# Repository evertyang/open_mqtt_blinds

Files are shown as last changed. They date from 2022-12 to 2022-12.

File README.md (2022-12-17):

# Open MQTT Blinds

An Arduino/ESP-based project to facilitate the automation of tilt wand blinds via MQTT



## Printables

View the 3D files here on [Printables](https://www.printables.com/model/334239-open-mqtt-blinds-wip). 

# Who is this for?

Anyone with a beginner’s level of mechatronics experience who wishes to automate their tilt wand blinds. 

![[https://www.blindschalet.com/bpa-423-industry-changes-stock-blinds-shades-december-2018.html](https://www.blindschalet.com/bpa-423-industry-changes-stock-blinds-shades-december-2018.html)](images/Untitled.png)

[https://www.blindschalet.com/bpa-423-industry-changes-stock-blinds-shades-december-2018.html](https://www.blindschalet.com/bpa-423-industry-changes-stock-blinds-shades-december-2018.html)

# Prerequisites

## Hardware

- Required:
    - [ESP8226 Board](https://smile.amazon.com/dp/B010N1SPRK?psc=1)
    - [28BYJ-48 Stepper Motor + ULN2003 Driver Combo](https://smile.amazon.com/dp/B01IP7IOGQ?psc=1)
    - [Buck Converter](https://www.amazon.com/LM2596-Converter-4-0-40V-1-25-37V-Voltmeter（2pcs）/dp/B085WC5G8N/ref=sr_1_3?crid=3Q47218J1UTVY&keywords=buck+converter&qid=1670349659&sprefix=buck+converter%2Caps%2C83&sr=8-3)
    - [Female-to-Female Jumper Wires](https://www.amazon.com/GenBasic-Piece-Female-Jumper-Wires/dp/B077N58HFK/?sprefix=female+to+female+dup,aps,110)
    - [12V DC power supply](https://www.amazon.com/100-240V-Transformers-Switching-Applications-Connectors/dp/B077PW5JC3/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,aps,108)
        - There is a good chance you have one of these lying around. Be sure the output is listed as 12v 3A.
    - [DC Barrel Jack to 2 Pin](https://www.amazon.com/dp/B07LFRDSB7?psc=1&ref=ppx_yo2ov_dt_b_product_details)
        - (if you didn’t purchase the above)
    - Metric screws:
        - (4) M2x8
        - (6) M2x4
        - (2) M3x4
- Nice to haves:
    - Access to a 3D printer OR the ability to get 3D printed parts
    - [Wire strippers](https://www.amazon.com/IRWIN-VISE-GRIP-2078300-Self-Adjusting-Stripper/dp/B000OQ21CA)
    - [Dupont connector kit to create your own length wires](https://www.amazon.com/IWISS-1550PCS-Connector-Headers-Balancer/dp/B08X6C7PZM/?sprefix=dupon,aps,102)
    - [Connector crimper for the above](https://www.amazon.com/dp/B017JU20Z6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)
    - [Ferrule crimping set so you don’t have to connect bare wires to pins](https://www.amazon.com/gp/product/B073TZ5BBG/ref=ppx_yo_dt_b_search_asin_title?ie=UTF8&psc=1)

## Software

- [Arduino IDE](https://www.arduino.cc/en/software)
- [Home Assistant](https://www.home-assistant.io) (HA)
    - I won’t go through specific installation steps here as it can be installed on a wide array of platforms
    - This project does necessitate the use of Add-Ons which means an OS or Supervised installation is required
        
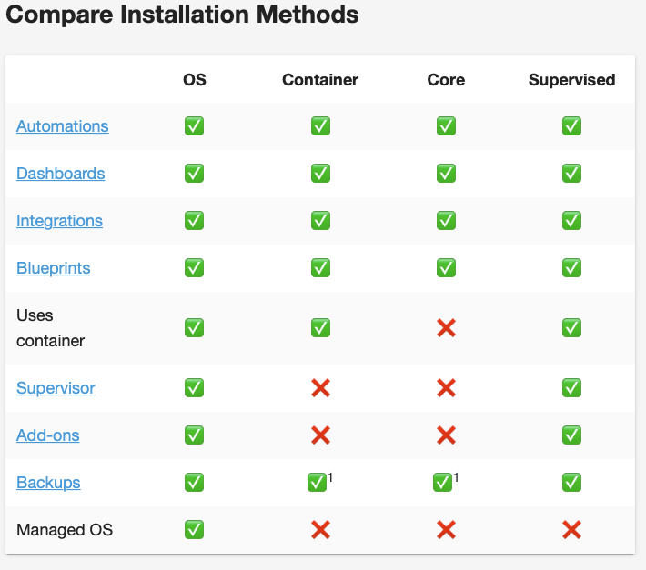
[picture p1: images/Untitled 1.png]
[https://www.home-assistant.io/installation/](https://www.home-assistant.io/installation/)
        
        
        [https://www.home-assistant.io/installation/](https://www.home-assistant.io/installation/)
        
    - I am running HA as a Linux VM
    - HA Installation documentation can be found [here](https://www.home-assistant.io/installation)
    - I found this [YouTube video](https://youtu.be/sVqyDtEjudk) to be very helpful when setting up HA
- [HA - MQTT Broker](https://www.home-assistant.io/integrations/mqtt/)
    - I will go through installation in the setup section

# Setup

## Home Assistant - MQTT Broker

1. It assumed at this point that you have Home Assistant installed and you are able to access the GUI via local IP address 
2. Navigate to *****Settings → Add-Ons → Add-Ons Store***** and look for **Mosquitto broker**
    
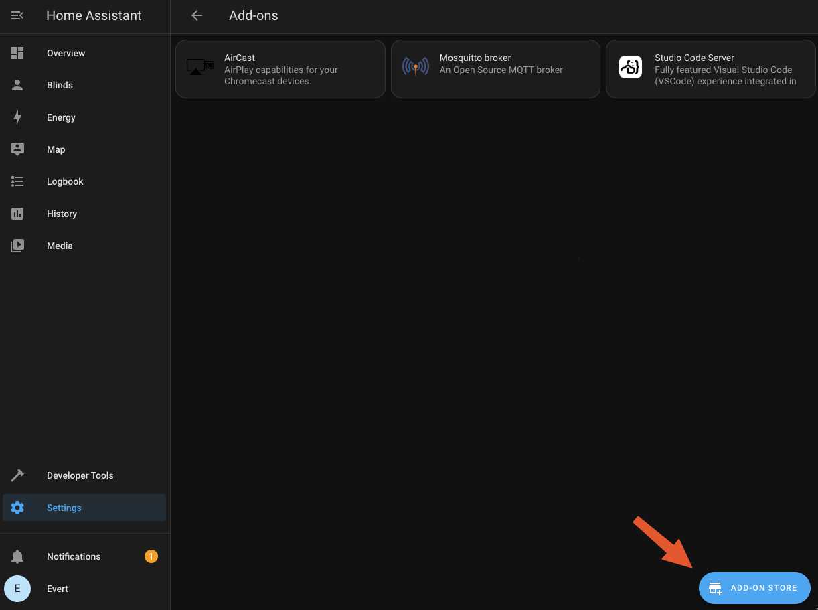
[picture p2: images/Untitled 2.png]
    
    
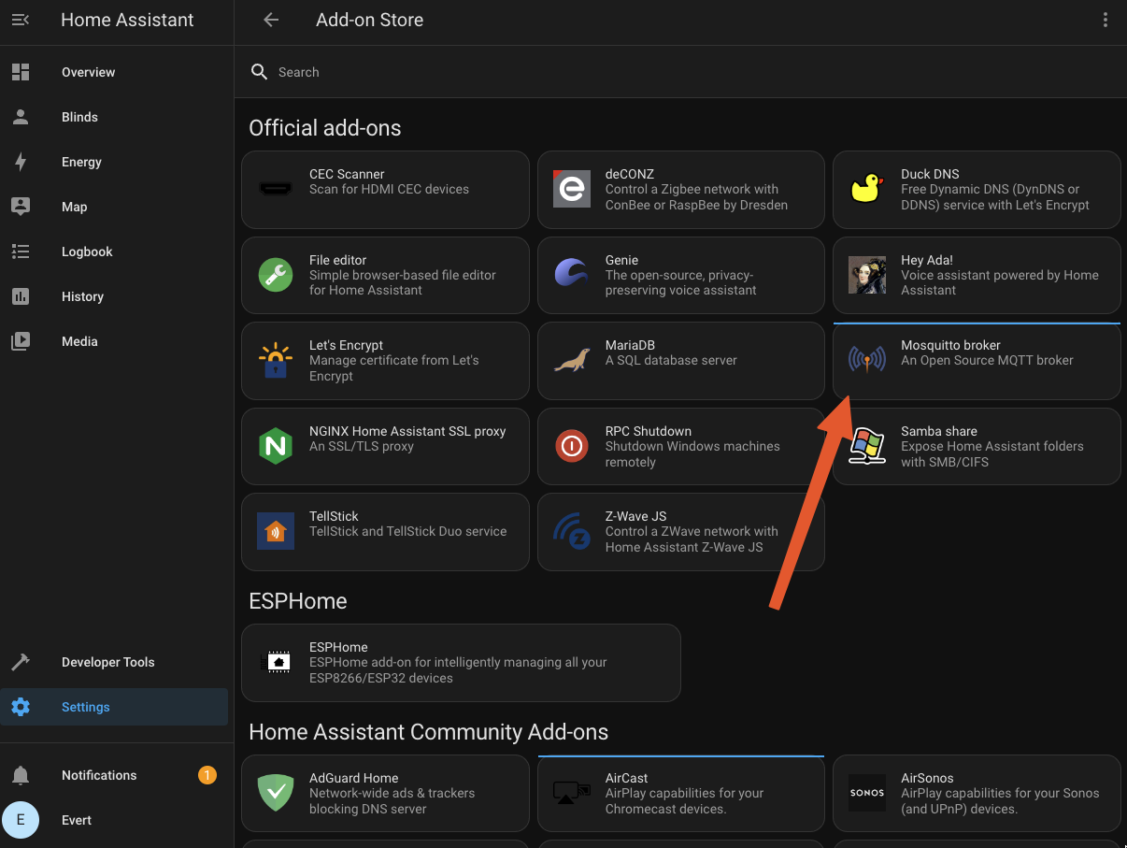
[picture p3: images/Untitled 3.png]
    
    
3. Click install and check the *Watchdog* option
    
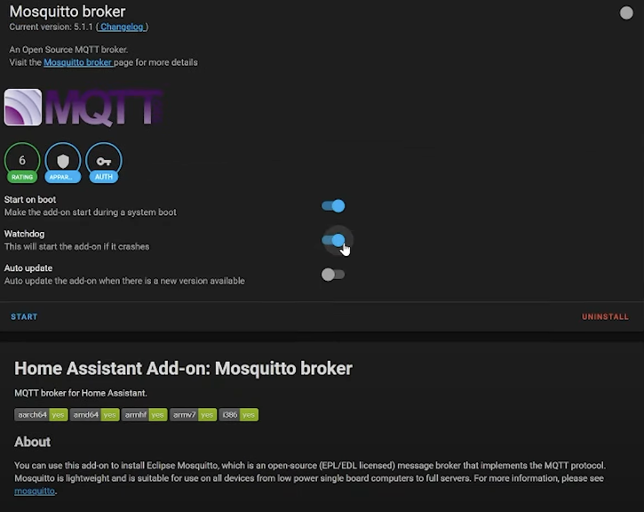
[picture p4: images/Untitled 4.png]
    
    
4. Create a MQTT user
    1. It’s considered best practice to create another user account for MQTT as it does not need admin access
    2. Navigate to ***Settings → People*** and click Add Person
        
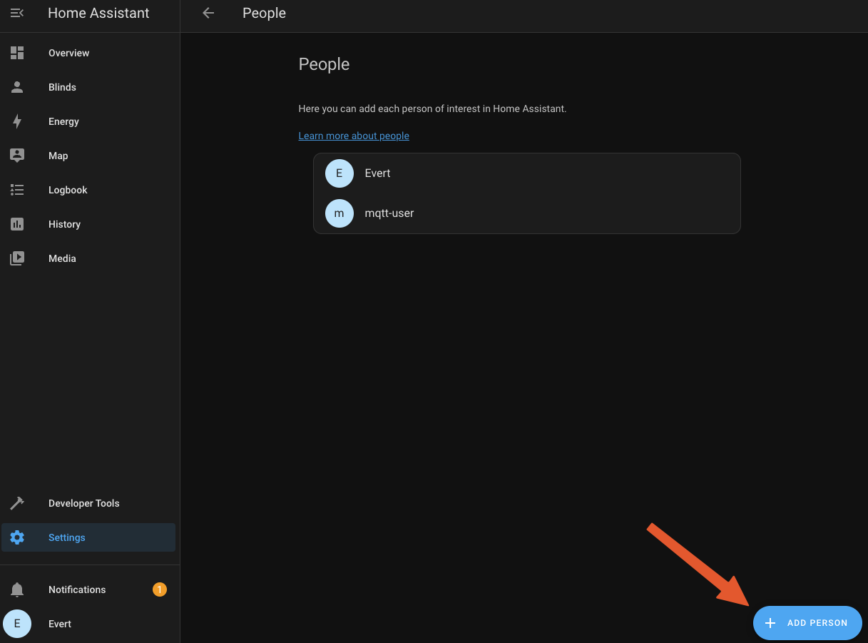
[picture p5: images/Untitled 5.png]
        
        
    3. Hit the *******Allow person to login******* toggle and create a MQTT user. I name mine `mqtt-user`. 
        
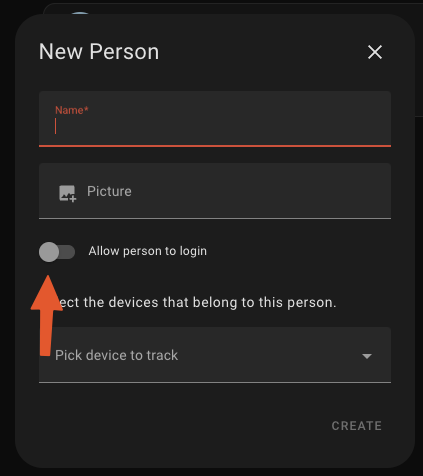
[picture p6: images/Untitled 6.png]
        
        
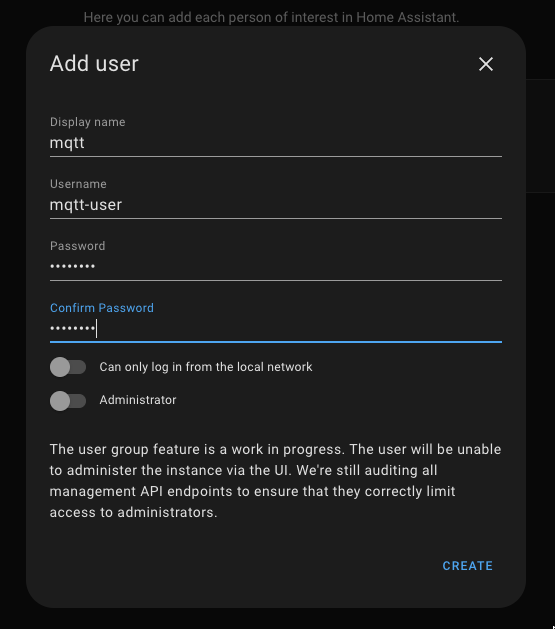
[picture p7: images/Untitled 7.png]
        
        
    4. Be sure to save these credentials in your password manager for later. 
5. Restart your Home Assistant instance via ***Settings → System*** and click Restart. 
    
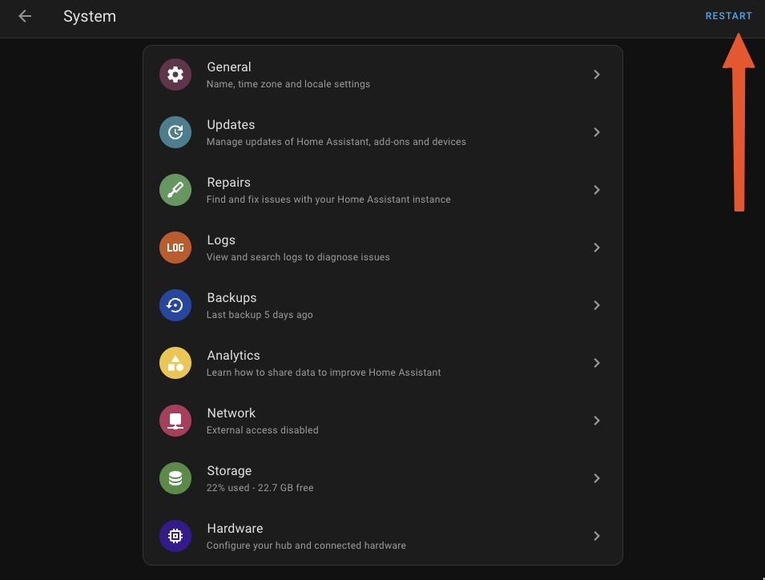
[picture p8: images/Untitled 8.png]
    
    
6. After restarting, you should see MQTT added to your Integrations Tab under ****Settings → Devices & Services**** 
    
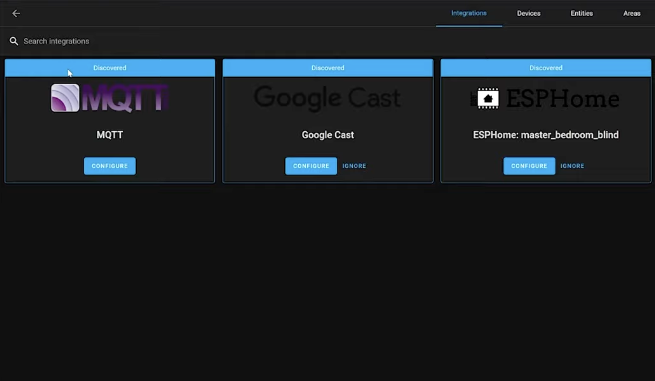
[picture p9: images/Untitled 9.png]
    
    
7. Click Configure and Submit followed by Configure once again to enter the integration
    
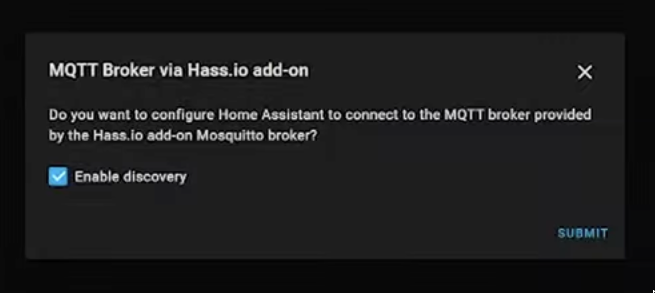
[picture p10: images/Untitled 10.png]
    
    
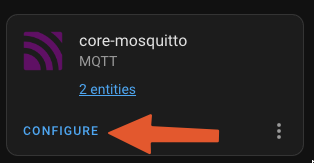
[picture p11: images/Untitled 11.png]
    
    
8. Click Re-Configure and add your MQTT user credentials from before
    
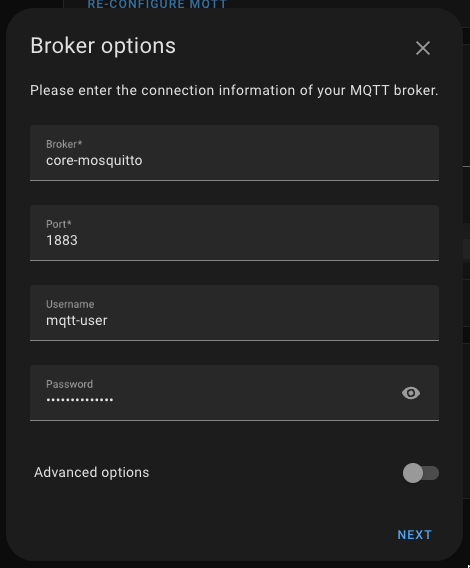
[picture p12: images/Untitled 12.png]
    
    
9. From this page you can send payloads via MQTT as well as monitor topics. This can be helpful later on for debugging any issues. 
    
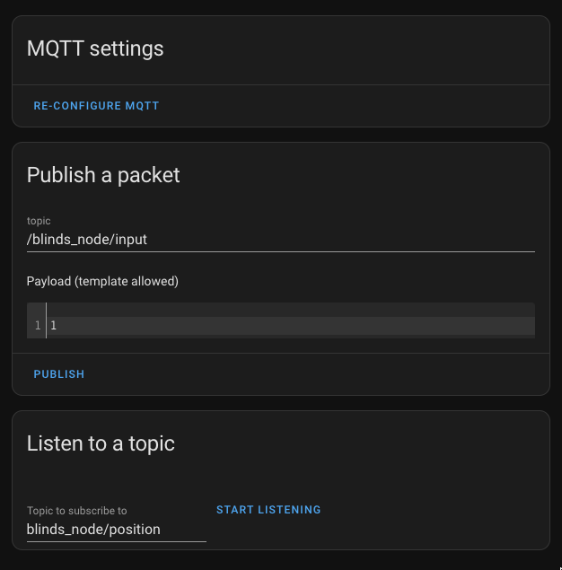
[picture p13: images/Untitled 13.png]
    

## Arduino IDE

1. Install Arduino IDE onto your platform of choice 
2. Add ESP8226 to board manager
    1. Navigate to preferences and paste `https://arduino.esp8266.com/stable/package_esp8266com_index.json` into ********Additional Board Manager URLs********
        
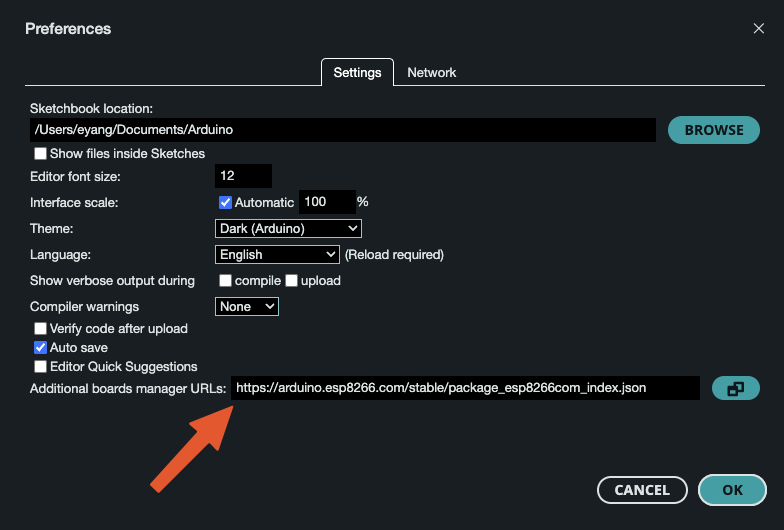
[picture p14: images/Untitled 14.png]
        
        
    2. Select ****NodeMCU 0.9**** as your board and hit OK. If you have connected your board via USB you can also select the port containing the board and hit OK. 
        
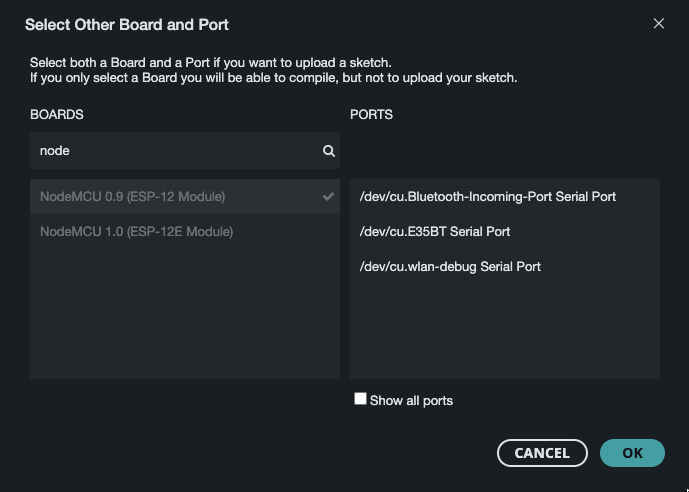
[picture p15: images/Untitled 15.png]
        
        
    3. If you prompted with this pop-up, click Yes
        
        
        
3. Import `mqtt_stepper.ino`
    1. Open `mqtt_stepper.ino` in Arduino IDE
    2. The required packages defined at the top of file should be automatically installed 
        1. If not, you will have to install them manually via the Library Manager
            
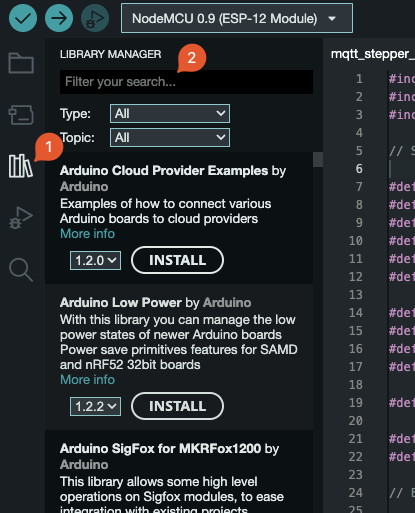
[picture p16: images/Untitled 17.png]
            
            
4. Fill out the user configuration section
    1. `USER_MQTT_URL` will be your Home Assistant GUI URL
    2. `USER_MQTT_USERNAME` and `USER_MQTT_PASSWORD` are the credentials you saved when creating a MQTT user
    3. `STEPS_PER_REV` should be set to `2048` if using a 28BY J-45 Stepper motor. If using another, see relevant technical information for correct number of steps
    4. `REVS_TO_CLOSE` will vary by blinds model. You can set this to `1` during the initial setup and tune it as necessary. 
    5. All other definitions can be left as written. 
    
    ```cpp
    // START USER CONFIG
    
    #define WIFI_SSID "your_wifi_name"
    #define WIFI_PASS "your_wifi_password"
    #define USER_MQTT_URL "xxx.xxx.xxx.xxx"
    #define USER_MQTT_PORT 1883
    #define USER_MQTT_USERNAME "your_mqtt_username"
    #define USER_MQTT_PASSWORD "your_mqtt_password"
    
    #define STEPPER_IN1 D5
    #define STEPPER_IN2 D6
    #define STEPPER_IN3 D7
    #define STEPPER_IN4 D8
    
    #define MSG_BUFFER_SIZE (50)
    
    #define STEPS_PER_REV 2048
    #define REVS_TO_CLOSE 8
    
    // END USER CONFIG
    ```
    
5. Connect the ESP8226 board via micro-USB if not already connected 
6. Click Upload and Arduino IDE will compile and send the sketch to the ESP8226 Board
    1. You should see it’s status in the output monitor 
    
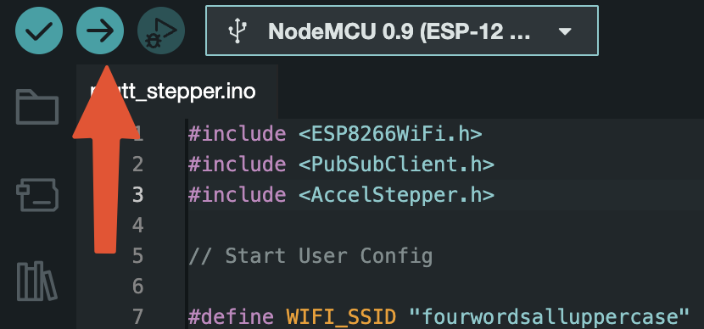
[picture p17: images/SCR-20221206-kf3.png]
    
    
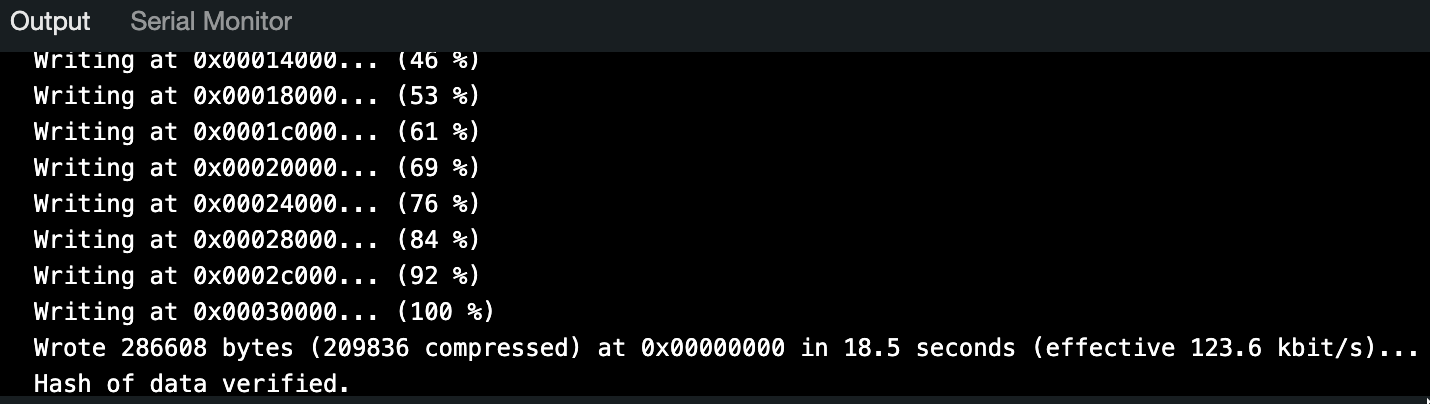
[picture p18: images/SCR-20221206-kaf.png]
    
    
7. Click the Serial Monitor button in the top right of screen and set the baud rate to `115200` 
    1. You should see connection status of board being outputted
    
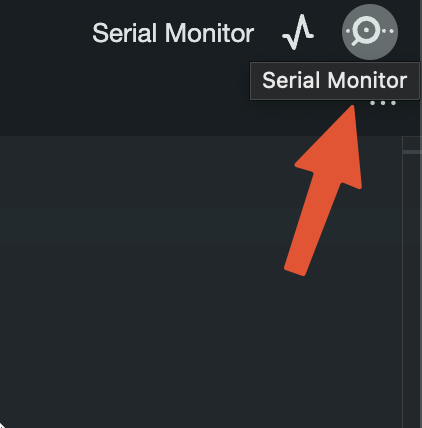
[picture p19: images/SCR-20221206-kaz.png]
    
    
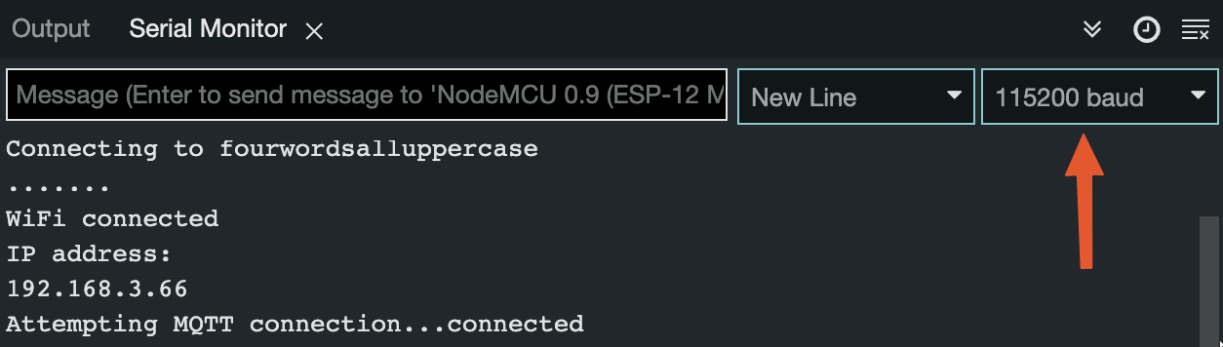
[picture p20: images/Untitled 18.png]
    
    
8. You can verify that it can receive MQTT payloads by sending one via the MQTT integration in Home Assistant
    
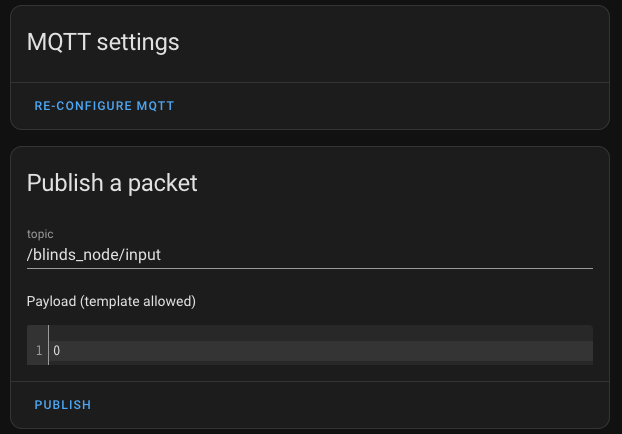
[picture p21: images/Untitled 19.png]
    
    
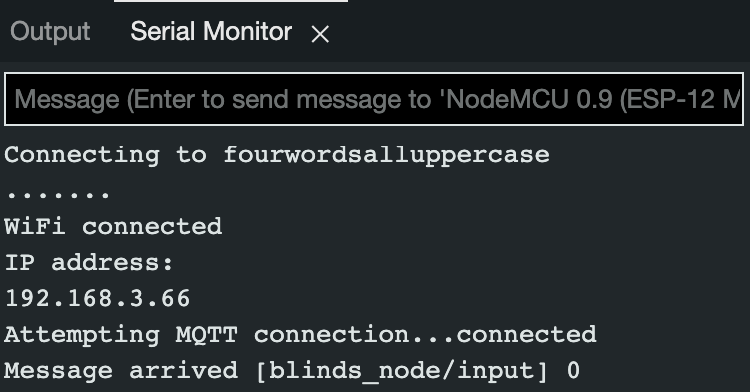
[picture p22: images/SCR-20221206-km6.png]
    

## Assembly

1. Download and print `controller_box.3mf` and `adapter.3mf`
    1. The controller box was designed to use as few supports as possible so material choice should not matter
    2. My parts were printed in Overture Matte White PLA at 210C
2. Place each board onto their respective stand-offs and screw on to secure boards in-place
    1. I found it easier to first screw each board down before assembling the box sides
        
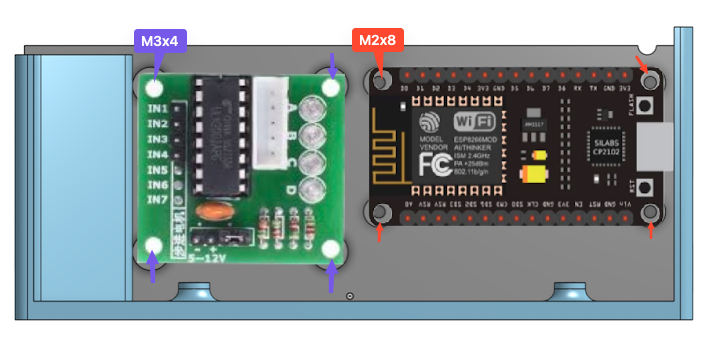
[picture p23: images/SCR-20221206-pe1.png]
NOTE: the ESP8226 board will be flipped when actually installed, with its pins facing away from the wall. Refer to wiring schematic for correct wire connections.
        
        
        NOTE: the ESP8226 board will be flipped when actually installed, with its pins facing away from the wall. Refer to wiring schematic for correct wire connections. 
        
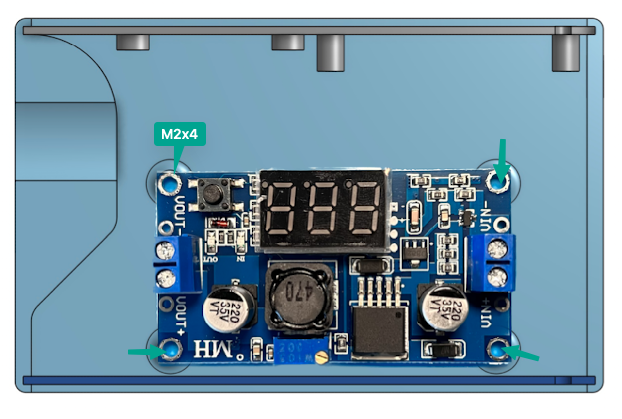
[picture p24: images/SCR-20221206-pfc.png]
        
        
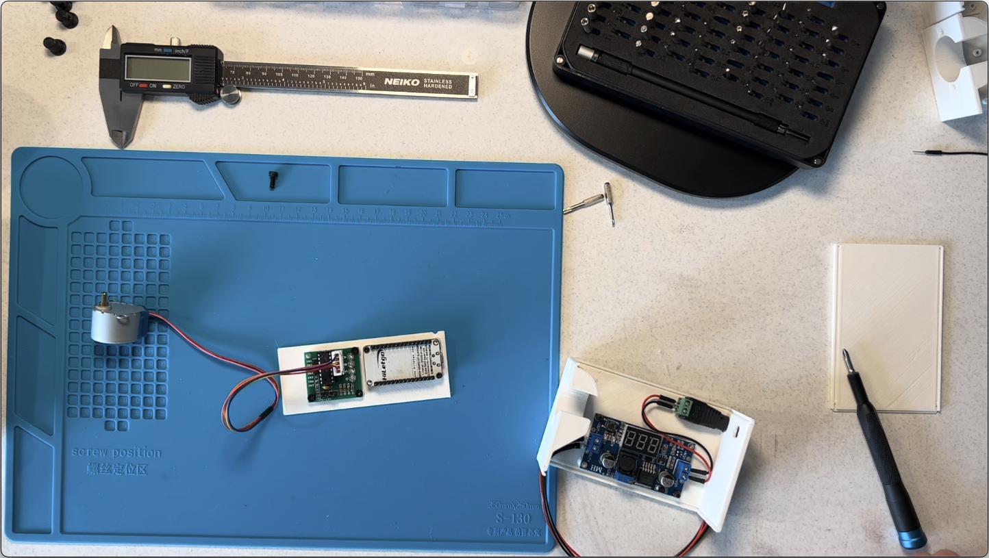
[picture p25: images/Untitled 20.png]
        
        
3. Wire up the components according the following schematic:
    1. Ensure that the buck convert is set to output 5V before connecting it any other components 
        
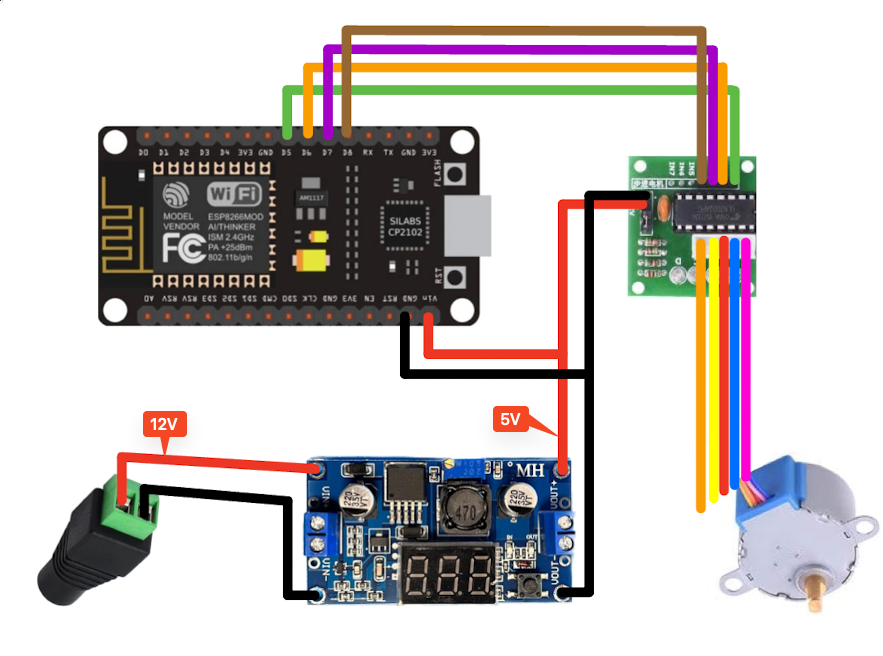
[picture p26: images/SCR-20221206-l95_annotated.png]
        
        
4. Once all connections have been made, plugging in power should result in the board and buck converter LEDs turning on
    
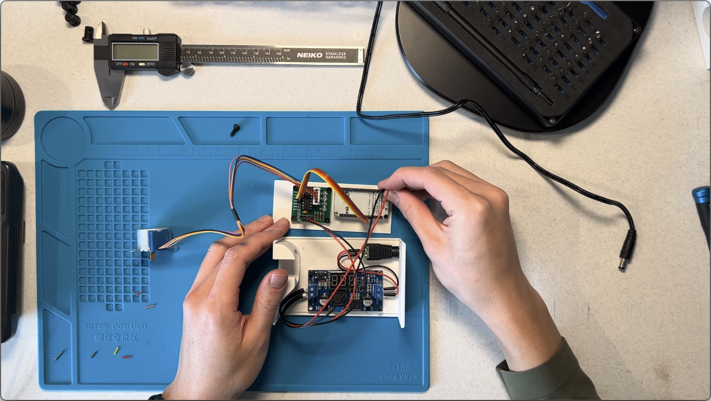
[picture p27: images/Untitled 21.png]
    
    
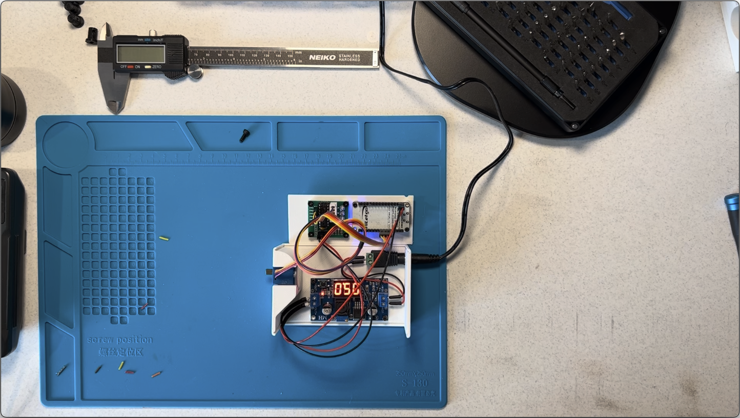
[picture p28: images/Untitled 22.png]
    
    
5. At this point, you can either continue with assembly of controller box or move onto Home Assistant configuration to validate it works final assembly
6. Finish box assembly by sliding each of the side walls into the grooves on either side of case
    1. There will be some resistance but take care not to use too much force to avoid breaking the case or electronics
        
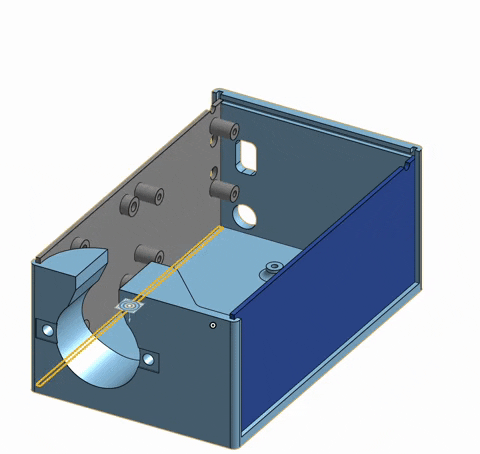
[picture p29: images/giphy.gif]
        
        
    2. Place the stepper motor into its slot and secure with (2) M3x4 screws
        
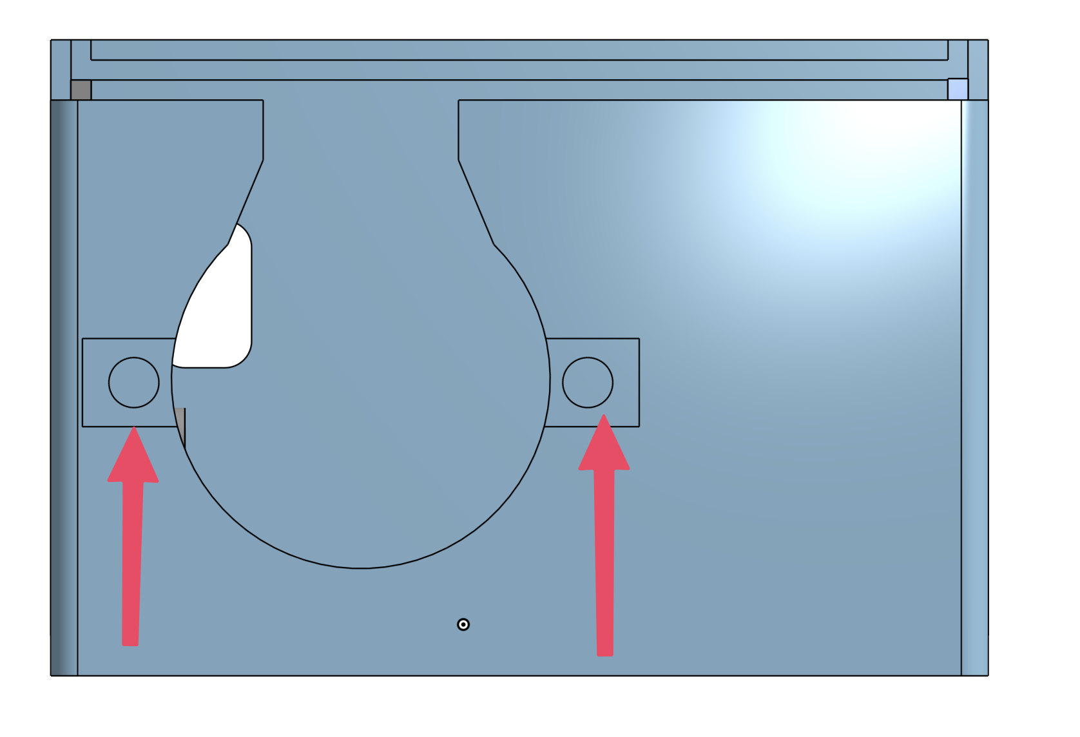
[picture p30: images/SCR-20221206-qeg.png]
        
        
    3. Top with lid and controller box assembly is complete 
        
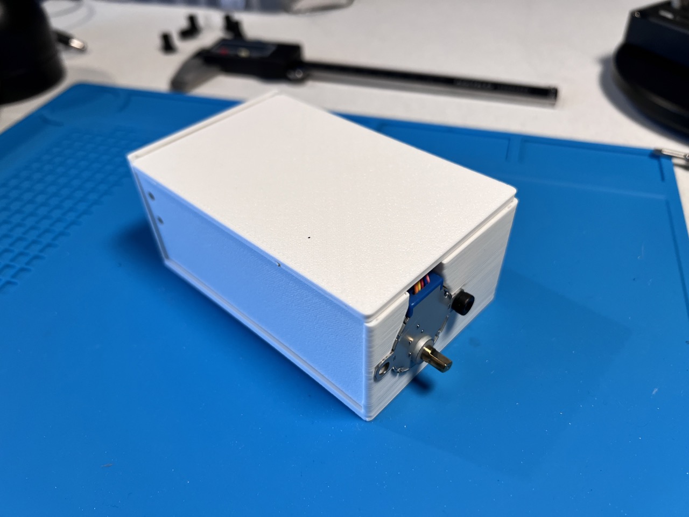
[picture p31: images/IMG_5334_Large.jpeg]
Prototype shown missing a screw
        
        
        Prototype shown missing a screw
        
7. Assemble the wand adapter
    1. Use a small screw driver or similarly shaped tool to depress the plastic notch securing the wand’s end cap 
        
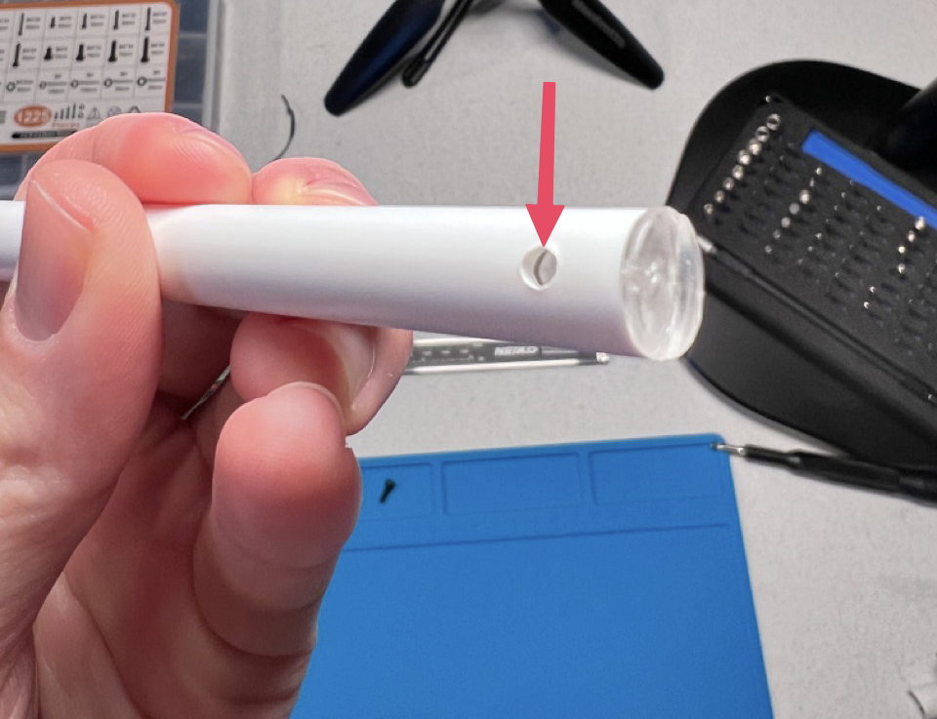
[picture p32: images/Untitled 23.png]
        
        
    2. Line up the adapter hole with the wand hole and secure with one M2x8 screw
8. Mounting the box
    1. Using your choice of double sided adhesive, mount the box under the wand taking care to keep the angle as roughly parallel to maximize torque
        
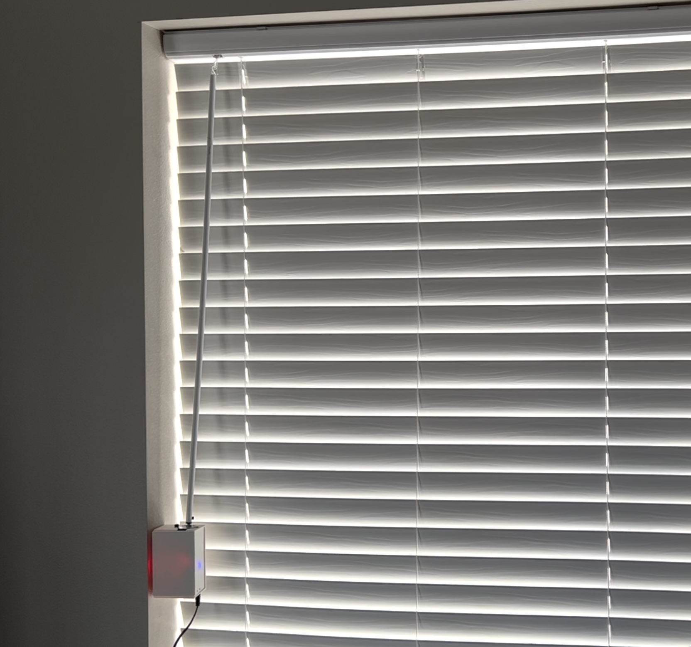
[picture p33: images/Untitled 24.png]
        
        
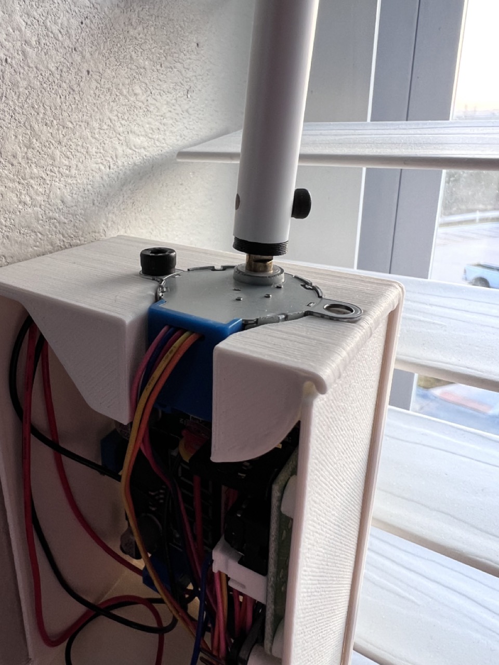
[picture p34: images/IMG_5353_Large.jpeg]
        
        
    2. 

## Home Assistant - Adoption

1. Return to the Home Assistant WebUI and navigate to Add-Ons Store once again to install Studio Code Server
    
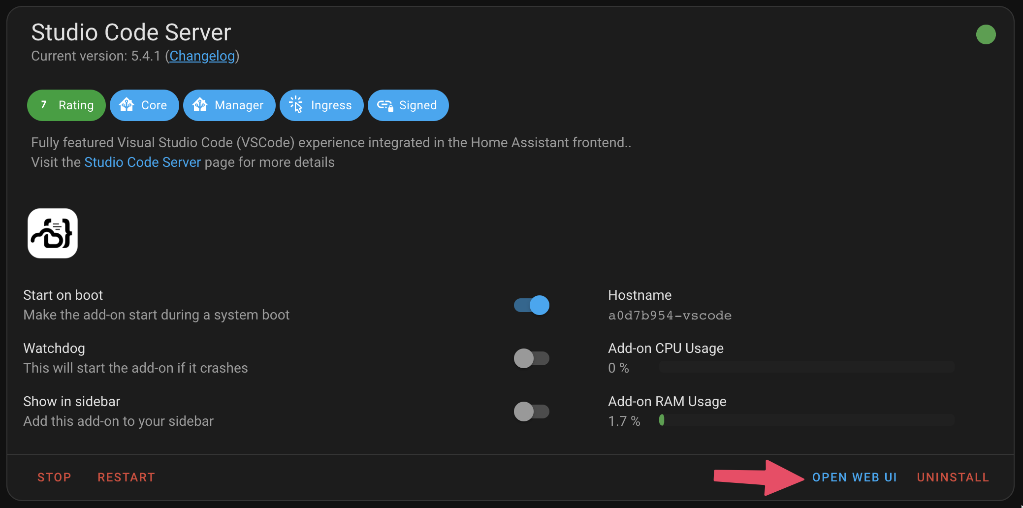
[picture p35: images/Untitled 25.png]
    
    
2. Open the Studio Code Server Web UI
    1. Once it has finished its first-time setup, use the Explorer to open `configuration.yaml`
        
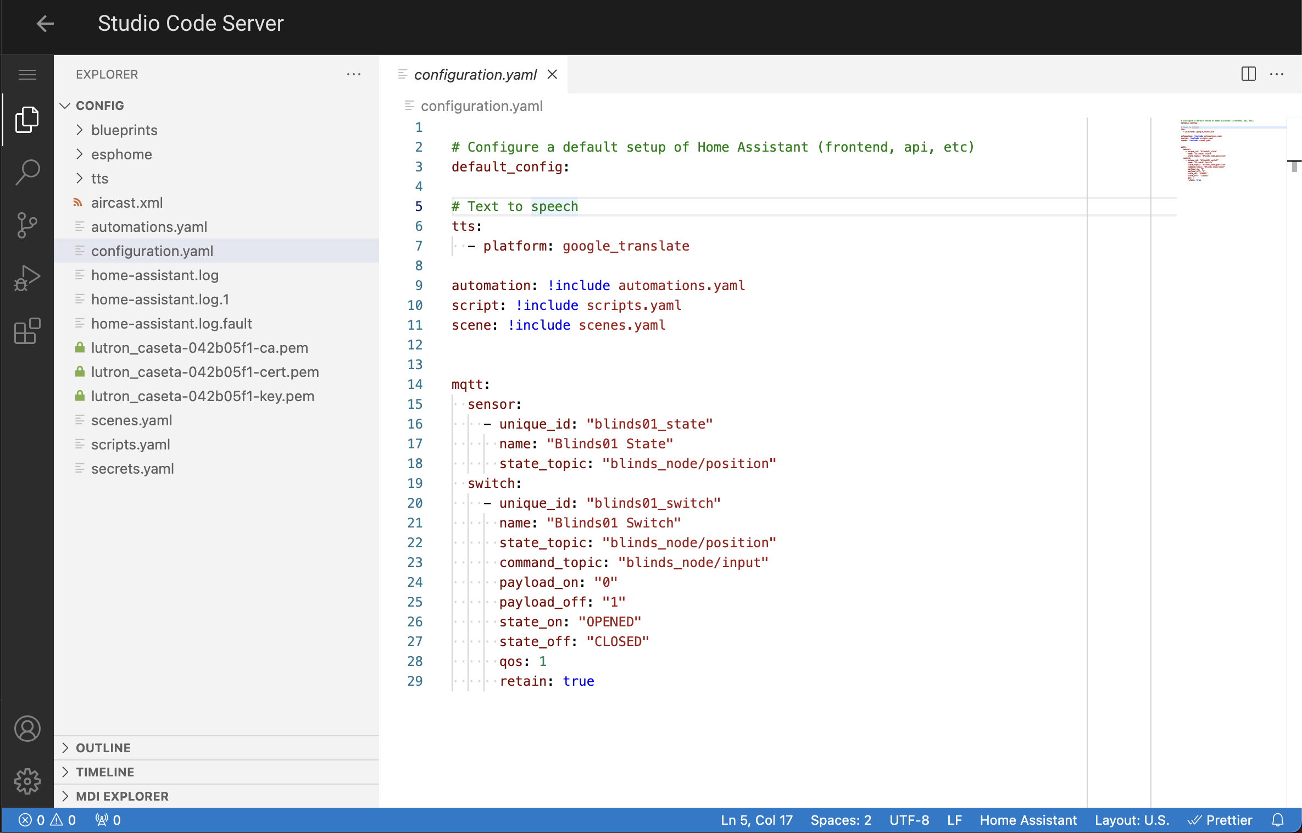
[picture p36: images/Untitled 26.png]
        
        
    2. Add the following code to the end of the line:
    
    ```yaml
    mqtt:
      sensor:
        - unique_id: "blinds01_state"
          name: "Blinds01 State"
          state_topic: "blinds_node/position"
      switch:
        - unique_id: "blinds01_switch"
          name: "Blinds01 Switch"
          state_topic: "blinds_node/position"
          command_topic: "blinds_node/input"
          payload_on: "0"
          payload_off: "1"
          state_on: "OPENED"
          state_off: "CLOSED"
          qos: 1
          retain: true
    ```
    
3. Restart your Home Assistant instance via *Settings* → *System* and click Restart.
4. You should now see 2 new entities added to your Home Assistant Dashboard
    
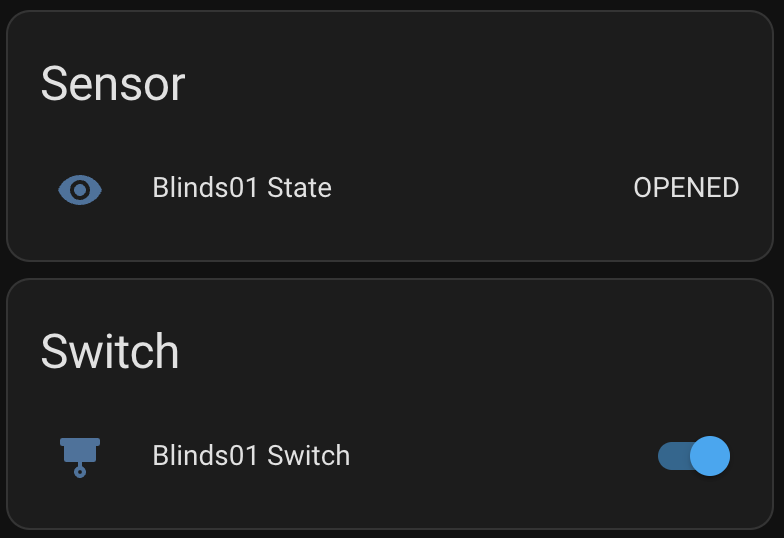
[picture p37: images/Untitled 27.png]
    
    
5. You should now able to send MQTT payloads via this switch to blinds controller 
    1. You can use MQTT integration to monitor payloads being sent 
        
        

## Adding it HomeKit

1. Install HomeKit Bridge integration following these [instructions](https://www.home-assistant.io/integrations/homekit#setup)
    1. Return to the integrations tab and hit Add Integration
    2. Search for Apple → HomeKit
    
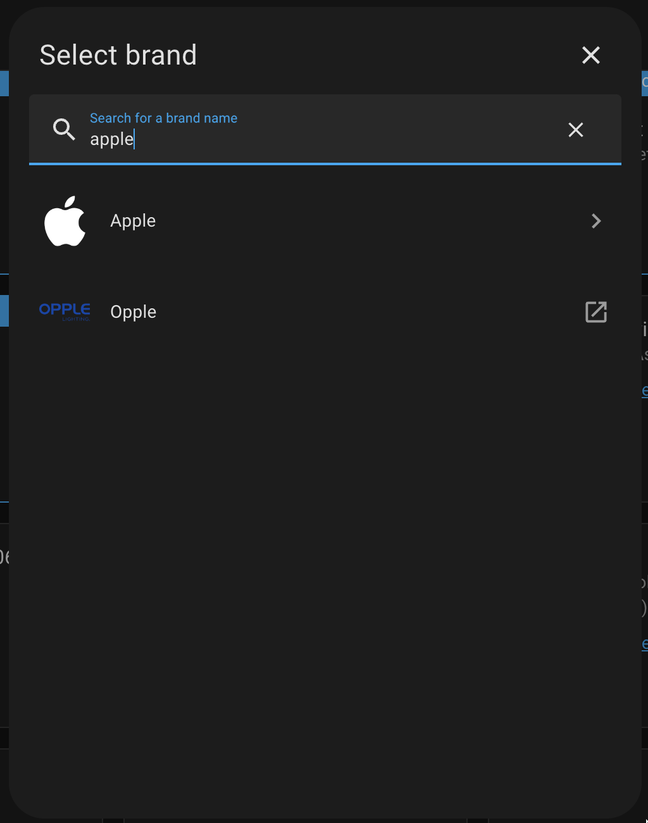
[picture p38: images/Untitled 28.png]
    	
    
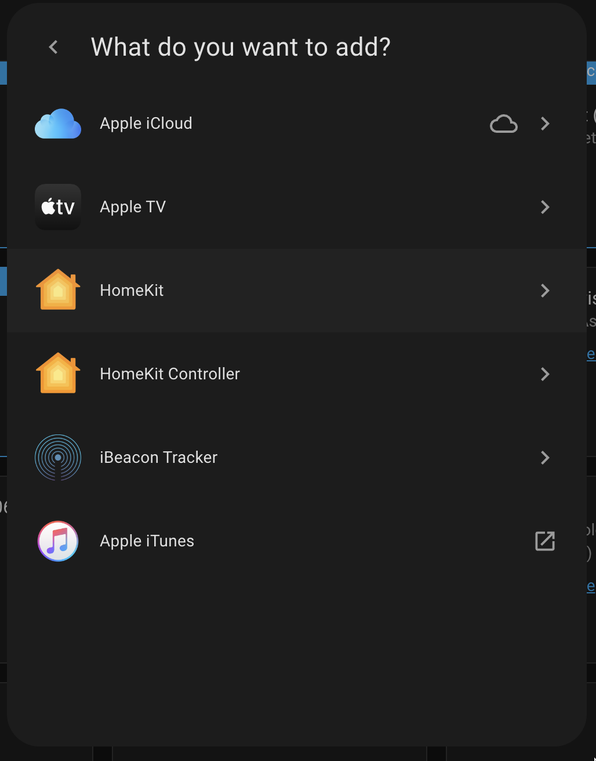
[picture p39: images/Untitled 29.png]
    	
    
2. Once the integration has been installed, select *HomeKit Mode* to `bridge` and *Inclusion Mode* to `include` 
    1. At a minimum include the Domains: `Switch` 
        
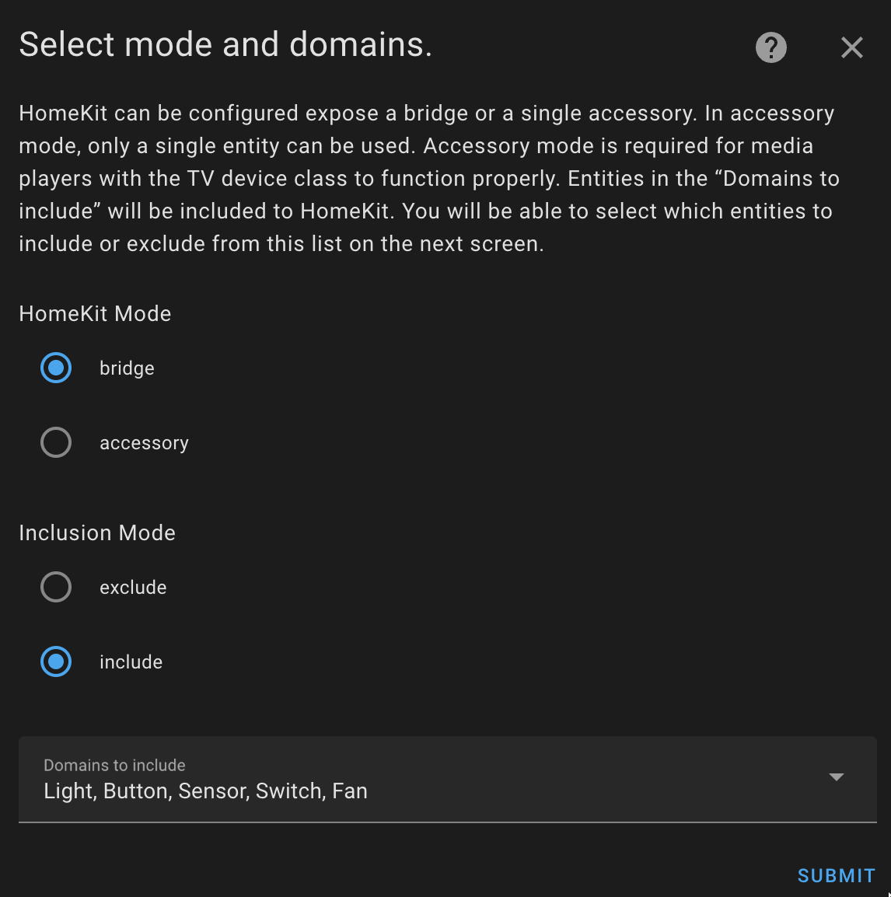
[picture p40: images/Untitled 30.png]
        
        
3. Search and select the new *Blinds01* entity
    
    
    
4. You should now see a new accessory added to your HomeKit
    


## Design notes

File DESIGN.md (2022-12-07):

# Motivation

The motivation behind this project came from a desire to automate blinds that was hindered by a relatively costly barrier to entry. Many commercial products on the market ranged anywhere from $75 to $750 per set of blinds. While DIY smart blinds are not a novel concept, many tutorials and blog posts focused on cord tilt blinds while I envisioned a simple motor to turn a tilt wand to change the shade level.

A CS50 final project was the perfect excuse to get started with  Arduino as well as diving deeper into Home Assistant which has presented a steep learning curve up until now.

# Decisions

## Arduino

Using an Arduino-based microcontroller seemed like a logical choice as it was significantly cheaper compared to RaspberryPis which was the leading alternative. During the research phase of this project, I also learned that there are countless other projects using ESP8266 boards specifically which allowed to narrow my focus. 

### mqtt_stepper.ino

```cpp
#include <ESP8266WiFi.h> // enables wifi connections https://arduino-esp8266.readthedocs.io/en/latest/esp8266wifi/readme.html
#include <PubSubClient.h> // enables MQTT protocol https://pubsubclient.knolleary.net
#include <AccelStepper.h> // library for better than stock stepper control http://www.airspayce.com/mikem/arduino/AccelStepper/

// ####### START USER CONFIG ######

#define WIFI_SSID "your_wifi_name"
#define WIFI_PASS "your_wifi_password"
#define USER_MQTT_URL "xxx.xxx.xxx.xxx"
#define USER_MQTT_PORT 1883
#define USER_MQTT_USERNAME "your_mqtt_username"
#define USER_MQTT_PASSWORD "your_mqtt_password"

// defines which pins on ESP will be used to connect with pins on stepper driver ULN2003
#define STEPPER_IN1 D5
#define STEPPER_IN2 D6
#define STEPPER_IN3 D7
#define STEPPER_IN4 D8

#define MSG_BUFFER_SIZE (50)

#define STEPS_PER_REV 2048 // specific to stepper motor 28BYJ-48 ULN2003 
#define REVS_TO_CLOSE 8    // this needs to be tuned by the user

// ###### END USER CONFIG ######

// declares all users defined variables 
const char* ssid = WIFI_SSID;
const char* password = WIFI_PASS;
const char* mqtt_server = USER_MQTT_URL;
const int   mqtt_port = USER_MQTT_PORT;
const char* mqtt_user = USER_MQTT_USERNAME;
const char* mqtt_pass = USER_MQTT_PASSWORD;

const int IN1 = STEPPER_IN1;
const int IN2 = STEPPER_IN2;
const int IN3 = STEPPER_IN3;
const int IN4 = STEPPER_IN4;

int stepsPerRev = STEPS_PER_REV;
int revsToClose = REVS_TO_CLOSE;
const int stepsToPhase = stepsPerRev * stepsToClose; // how many steps it will take to close blinds 

AccelStepper myStepper(AccelStepper::FULL4WIRE, IN1, IN3, IN2, IN4); // defining stepper 
WiFiClient espClient; // defining wificlient object
PubSubClient client(espClient); // mqtt client object 
unsigned long lastMsg = 0;

char msg[MSG_BUFFER_SIZE];
int value = 0;

// connects board to wifi 
void setup_wifi() 
{
  delay(10);
  Serial.println();
  Serial.print("Connecting to ");
  Serial.println(ssid);

  WiFi.mode(WIFI_STA);
  WiFi.begin(ssid, password);

  while (WiFi.status() != WL_CONNECTED) 
  {
    delay(500);
    Serial.print("."); // waiting...
  }

  randomSeed(micros());

  Serial.println("");
  Serial.println("WiFi connected");
  Serial.println("IP address: ");
  Serial.println(WiFi.localIP()); // output local IP address to serial 
}

// waits for MQTT payload 
void callback(char* topic, byte* payload, unsigned int length) 
{
  Serial.print("Message arrived [");
  Serial.print(topic);
  Serial.print("] ");
  for (int i = 0; i < length; i++) 
  {
    Serial.print((char)payload[i]);
  }
  Serial.println();

  // check payload
  if ((char)payload[0] == '1') 
  {
    digitalWrite(BUILTIN_LED, LOW);  // turn the LED on and close blinds if message is '1'
    myStepper.moveTo(-stepsToPhase);
    client.publish("blinds_node/position", "CLOSED");
  } 
  else 
  {
    digitalWrite(BUILTIN_LED, HIGH);  // turn the LED and open blinds if message is '0'
    myStepper.moveTo(0);
    client.publish("blinds_node/position", "OPENED");
  }
}

// conncets to MQTT broker and subscribes to topic 
void reconnect() 
{
  // loop until reconnected
  while (!client.connected()) 
  {
    Serial.print("Attempting MQTT connection...");
    // create a random client ID
    String clientId = "ESP8266Client-";
    clientId += String(random(0xffff), HEX);
    // attempt to connect
    if (client.connect(clientId.c_str(), mqtt_user, mqtt_pass)) 
    {
      Serial.println("connected");
      // once connected, publish an announcement...
      client.publish("blinds_node/log", "hello world");
      // ... and resubscribe
      client.subscribe("blinds_node/input");
    } 
    else 
    {
      Serial.print("failed, rc=");
      Serial.print(client.state());
      Serial.println(" try again in 5 seconds");
      // wait 5 seconds before retrying
      delay(5000);
    }
  }
}

void setup() 
{
  myStepper.setMaxSpeed(600.0); // defines stepper max speed; it is capable of a speed of 750 it tends to skip 
  myStepper.setAcceleration(50.0); // defines max acceleration 
  pinMode(BUILTIN_LED, OUTPUT);  // initialize the BUILTIN_LED pin as an output
  Serial.begin(115200);
  setup_wifi();
  client.setServer(mqtt_server, mqtt_port);
  client.setCallback(callback);
}

void loop() 
{
  if (!client.connected()) // tries to reconnect if not connected 
  { 
    reconnect();
  }
  client.loop();
  myStepper.run();
}
```

## MQTT

MQTT (Message Queuing Telemetry Transport) is a lightweight communication protocol that is used for IoT (Internet of Things) communication. It is designed to be simple and efficient, making it ideal for low-power and low-bandwidth devices, such as sensors and actuators. MQTT is a publish/subscribe protocol, which means that devices can both publish data to a broker (server) and subscribe to data from the broker. This allows for efficient communication between devices, as they only receive the data they are interested in.

## Home Assistant

Home Assistant is an open-source home automation platform that allows users to control and automate various devices in their home. Home Assistant has a large and active community of users who contribute to the platform by creating custom integrations and add-ons for a wide range of devices and services. While I’ve been using Home Assistant prior to this project, its a logical choice to tie in a MQTT broker a other IoT devices. 

## YAML

YAML (Yet Another Markup Language) is a human-readable data serialization language that is commonly used for configuration files, but can also be used in data storage and communication. It is designed to be easy to read and write, and is therefore often used as an alternative to JSON (JavaScript Object Notation) or XML (eXtensible Markup Language). I didn’t  have any choice but to use YAML to add custom MQTT devices. Some users in the Home Assistant community begrudge the YAML editing aspect.  

### configuration.yaml

```yaml
# Configure a default setup of Home Assistant (frontend, api, etc)
default_config:

# Text to speech
tts:
  - platform: google_translate

automation: !include automations.yaml
script: !include scripts.yaml
scene: !include scenes.yaml

# start custom configuration 
mqtt:
  sensor:
    - unique_id: "blinds01_state" # this must be unique in order to enable it in the dashboard
      name: "Blinds01 State"
      state_topic: "blinds_node/position"
  switch:
    - unique_id: "blinds01_switch" # this must be unique in order to enable it in the dashboard
      name: "Blinds01 Switch"
      state_topic: "blinds_node/position"
      command_topic: "blinds_node/input"
      payload_on: "0" # this paylod opens the blinds 
      payload_off: "1" # this payload closes the blinds 
      state_on: "OPENED" # looks at topic 'blinds_node/position' and if it is 'OPENED', set state to on
      state_off: "CLOSED" # looks at topic 'blinds_node/position' and if it is 'CLOSED', set state to off
      qos: 1 # keeps sending MQTT payload until it acknolwedged 
      retain: true # enables home assistant to know that the blinds are still open/closed 
```

## Stepper Motors vs DC Motors

2 common Arduino project motors are DC and stepper motors. Stepper motors move in discrete steps, allowing for precise control of the output shaft's position and speed. On the other hand, DC motors use direct current (DC) to generate rotational motion and are typically less precise than stepper motors. Stepper motors are commonly used in applications where precise positioning is required, such as 3D printers and CNC machines. DC motors are commonly used in applications where speed and cost are more important than precise positioning, such as electric vehicles and fans. Since precision was more key for this project, stepper motors were an obvious choice. 

## 3D Printing

While this project would most likely still be possible without the use of a 3D printer, it has definitely made it significantly easier. Being able to start with initial CAD design and then iterating on it over the course of a week is invaluable. 

# Bill of Materials

| Item | Price | Quantity  | Price / Per | URL |
| --- | --- | --- | --- | --- |
| Kuman Stepper Motor 28BYJ-48 ULN2003 5V Stepper Motor + ULN2003 Driver Board | 13.99 | 5 | 2.798 | https://smile.amazon.com/dp/B01IP7IOGQ?psc=1 |
| HiLetgo 2pcs ESP8266 NodeMCU | 12.69 | 2 | 6.345 | https://smile.amazon.com/dp/B010N1SPRK?psc=1 |
| Female Barrel Power Jack to 2 Pin/Way | 7.39 | 20 | 0.3695 | https://www.amazon.com/dp/B07LFRDSB7?psc=1&ref=ppx_yo2ov_dt_b_product_details |
| Qunqi Buck Converter | 8.59 | 5 | 1.718 | https://www.amazon.com/dp/B014Y3OT6Y?psc=1&ref=ppx_yo2ov_dt_b_product_details |
| Songhe Buck Converter | 12.88 | 5 | 2.576 | https://www.amazon.com/LM2596-Converter-4-0-40V-1-25-37V-Voltmeter（2pcs）/dp/B085WC5G8N/ref=sr_1_3?crid=2F85HQL6MKYPP&keywords=buck+converter&qid=1670350081&sprefix=buck+converter%2Caps%2C86&sr=8-3 |

As configured, the total price per controller is $12.38. While this is significantly cheaper than any commercial product, there are many costs not considered including the many hours development as well as assembly and setup time. Also not included are many of the items I already owned including a 3D printer, filament, Home Assistant VM, and miscellaneous other tools. 

The inclusion of buck converters is due the fact that my soldering iron failed on me midway through the project so I was not able to use the cheaper Qunqi one. On one hand, it made this project easier as it doesn’t include any soldering. However, I was forced to use a larger buck converted that I already had which caused the case to be larger than initially anticipated. 

# Limitations and Next Steps

As with all projects, the deadline for this drew faster than expected so I wasn’t able to achieve all my goals. In no particular order, here is a list of features I have not yet implemented:

- open blinds to a certain percentage
- make controller box battery powered
- add a solar panel to charge the battery
- miniaturize the case
- design a better closing mechanism for the case to prevent warping
- remove LEDs / mitigate light leakage
- miniaturize case so that it can fit in the OEM blinds housing
- make it easier to adopter multiple controllers
- enable support for Google Assistant / Alexa
- optimize for power efficiency

I look forward to making this project available to public to see what improvements can be made and how it can help others automate their homes. 

# Acknowledgments

The following resources were invaluable in researching and studying for this project: 

[https://github.com/thehookup/Motorized_MQTT_Blinds](https://github.com/thehookup/Motorized_MQTT_Blinds)

 [https://hackaday.io/project/183279-accelstepper-the-missing-manual](https://hackaday.io/project/183279-accelstepper-the-missing-manual)

[https://randomnerdtutorials.com/esp8266-nodemcu-stepper-motor-28byj-48-uln2003/](https://randomnerdtutorials.com/esp8266-nodemcu-stepper-motor-28byj-48-uln2003/)

[https://youtu.be/dqTn-Gk4Qeo](https://youtu.be/dqTn-Gk4Qeo)

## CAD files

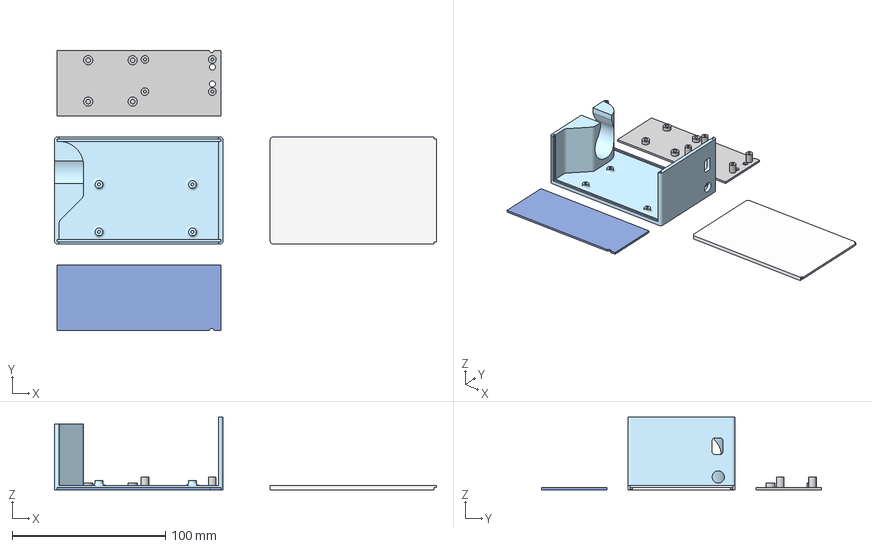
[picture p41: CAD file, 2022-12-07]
3MF/controller_box.3mf
249.2 x 183.0 x 47.5 mm
blinds_box_top
blinds_box_front
blinds_box_back
blinds_box_bottom

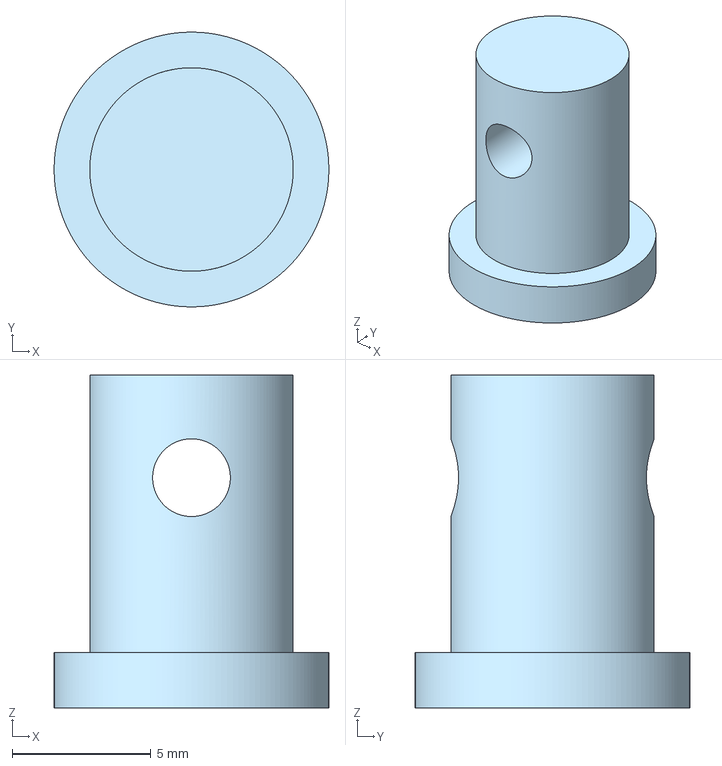
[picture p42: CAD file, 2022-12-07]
3MF/adapter.3mf
9.90 x 9.90 x 12.0 mm
